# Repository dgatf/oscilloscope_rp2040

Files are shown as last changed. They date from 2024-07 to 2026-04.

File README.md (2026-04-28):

# Oscilloscope RP2040 - OpenHantek protocol

An oscilloscope for the RP2040 that implements the [OpenHantek6022](https://github.com/OpenHantek/OpenHantek6022) protocol.

## Specifications

- Up to 1 MS/s
- 2 channels
- OpenHantek6022-compatible protocol

## Usage

1. Upload the [oscilloscope.uf2](#binaries) firmware to the RP2040.

2. Install OpenHantek. OpenHantek6022 needs RP2040 support:
   [OpenHantek6022 fork](https://github.com/dgatf/OpenHantek6022)

   - Build OpenHantek following the project instructions.
   - Or download prebuilt [binaries](https://github.com/dgatf/OpenHantek6022/releases).

3. The external circuit is optional. If you are **not** using the [external circuit](#external-circuit), copy [RP2040_0_calibration.ini](RP2040_0_calibration.ini) to:

   - Linux: `~/.config/OpenHantek/`
   - Windows: `%USERPROFILE%\.config\OpenHantek`

4. Launch the modified version of OpenHantek6022.

## Pins

- Channel 1: GPIO 26
- Channel 2: GPIO 27
- Calibration signal: GPIO 22
- No conversion: GPIO 19
- Debug enable/disable: GPIO 18
- Debug output: GPIO 16

Without the [external circuit](#external-circuit), the input voltage on GPIO 26 and GPIO 27 must stay between 0 V and 3.3 V.

Debug output is available on GPIO 16 at 115200 bps. To enable debug output, connect GPIO 18 to GND at boot.

The LED is on during capture.

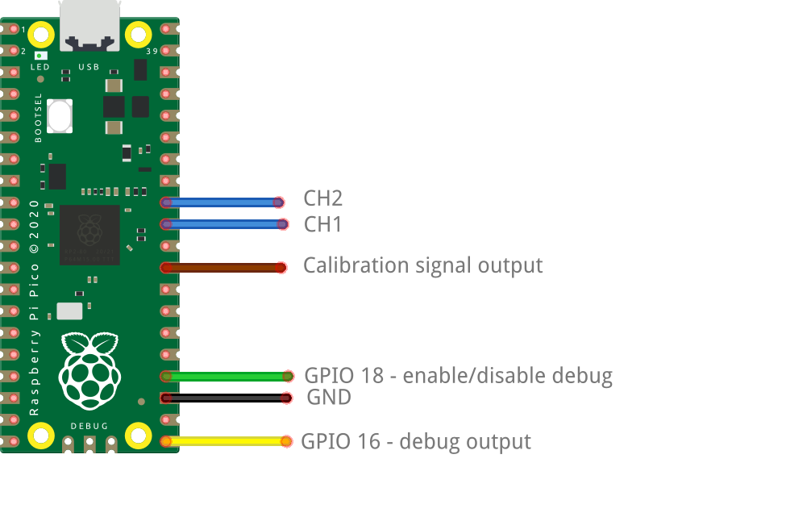
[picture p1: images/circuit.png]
<p align="center"><br></p>

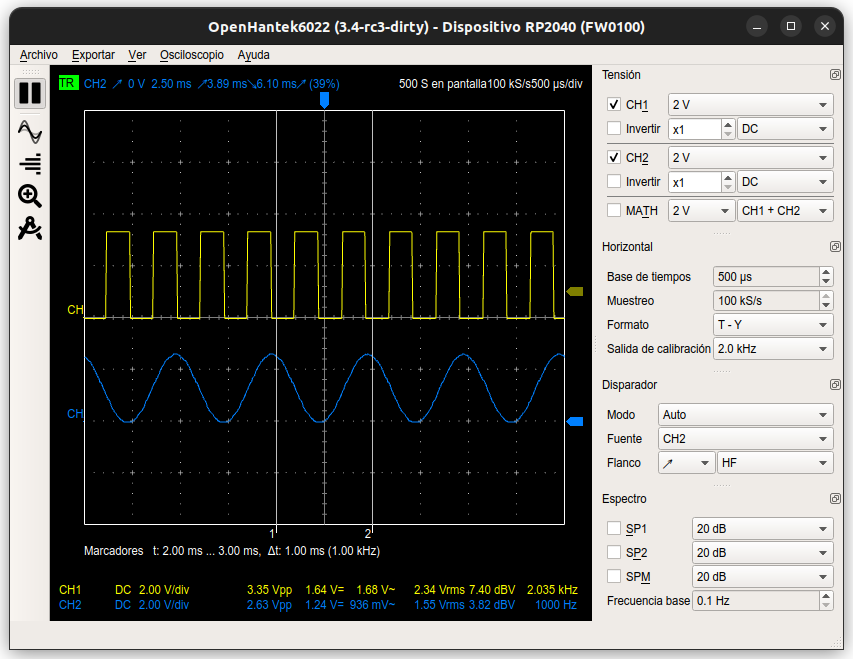
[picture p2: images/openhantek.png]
<p align="center"><br></p>

## External circuit

The external circuit adapts the input signal from ±5 V to the RP2040 ADC range and adds AC/DC coupling.

Signal conversion:

- Step down from 5 V to 3.3 V
- AC/DC coupling
- Optional gain stage
- Center zero voltage at VCC/2

The RP2040 ADC is 12-bit, while OpenHantek expects 8-bit samples. The firmware scales the ADC value from 12 bits to 8 bits. Maximum digital gain is 16. For higher gains, use an additional analog gain stage before centering the signal.

### Materials

- 1 x CD4066 analog switch
- 1 x LM358 op-amp
- 2 x 100 nF ceramic capacitor
- 6 x 10 kΩ resistor
- 2 x 33 kΩ resistor
- 2 x 22 kΩ resistor

If the calibration file was previously copied to the OpenHantek config folder, delete it when using the external circuit.

### Pins

- AC/DC coupling channel 1: GPIO 20
- AC/DC coupling channel 2: GPIO 21

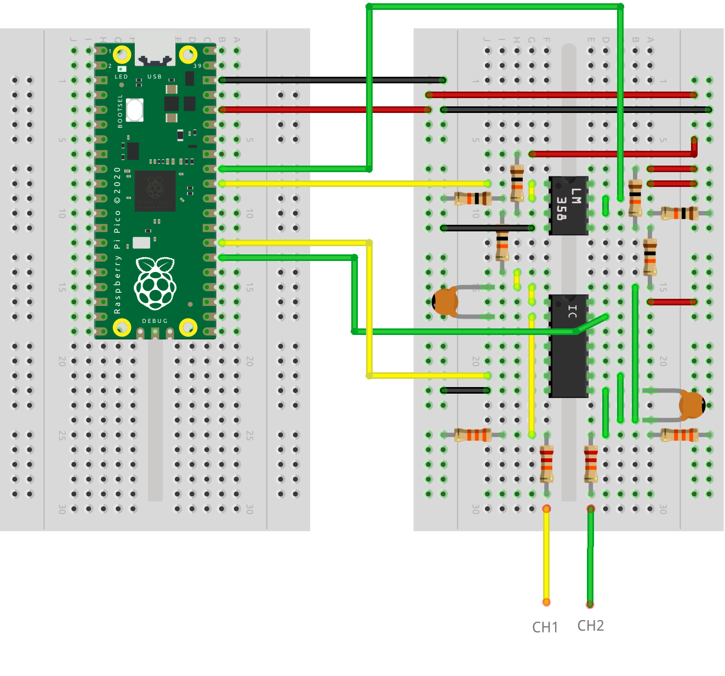
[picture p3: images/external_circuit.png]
<p align="center"><br></p>

## Calibration file OpenHantek

If the external circuit is not used, OpenHantek needs a calibration file to map the RP2040 0-3.3 V ADC input to the expected ±5 V range.

Copy [RP2040_0_calibration.ini](RP2040_0_calibration.ini) to:

- Linux: `~/.config/OpenHantek/`
- Windows: `%USERPROFILE%\.config\OpenHantek`

The calibration file sets:

- Offset: `-127`
- Gain: `0.33`

If using the external circuit, set offsets to `0` and gains to `1`, or delete the calibration file.

## Notes

- The firmware uses fixed-length USB transfers. Streaming is implemented at the application level by re-arming transfers.
- Double-buffered USB transfers improve stability and reduce buffer overflows.
- At 1 MS/s, operation is usable but may still show occasional dropped samples due to USB full-speed bandwidth limits.
- For rates above ~500 kS/s, the ADC operates at higher clock speeds, which may slightly affect accuracy.
- **Linux:** if the device is not detected, install the appropriate [udev rules](udev/99-openhantek.rules) under `/etc/udev/rules.d/` and reconnect the device.
- **Windows:** you may need to install a WinUSB-compatible driver using Zadig.

Example Linux setup:

```bash
sudo cp udev/99-openhantek.rules /etc/udev/rules.d/
sudo udevadm control --reload-rules
sudo udevadm trigger
```

## Binaries

- [RP2040](https://github.com/dgatf/oscilloscope_rp2040/releases)
- [OpenHantek (RP2040)](https://github.com/dgatf/OpenHantek6022/releases)

## References

- [OpenHantek6022](https://github.com/OpenHantek/OpenHantek6022)
- [libsigrok](https://github.com/sigrokproject/libsigrok)
- Das Oszi Protocol - eLinux.org
- [Usb device library](https://github.com/dgatf/usb_library_rp2040)

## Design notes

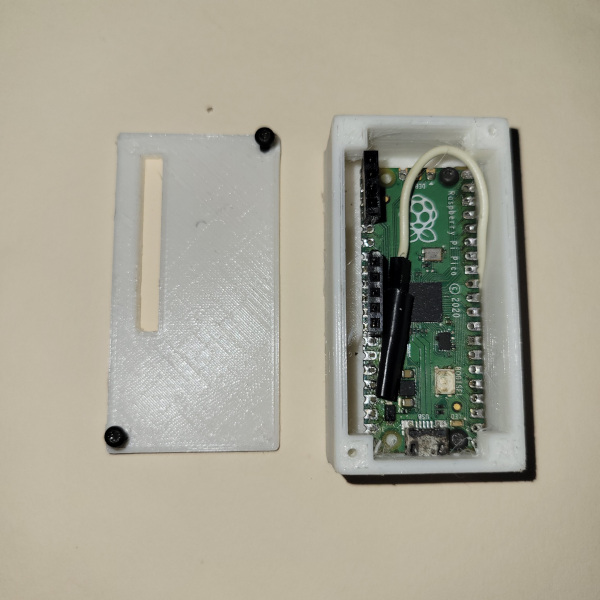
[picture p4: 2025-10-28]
images/case_open.jpg

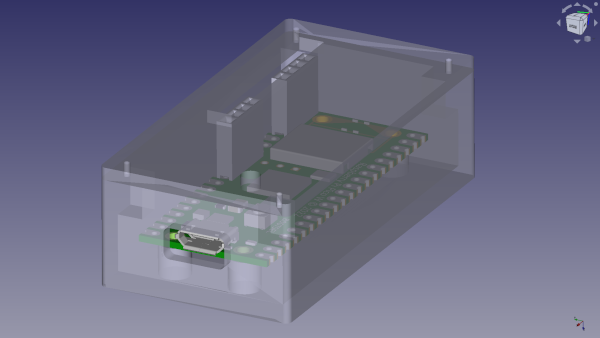
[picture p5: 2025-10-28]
images/3d_model.png

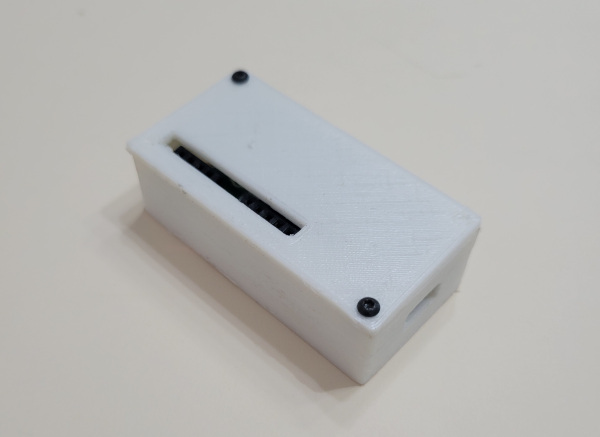
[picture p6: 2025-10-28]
images/case_closed.jpg

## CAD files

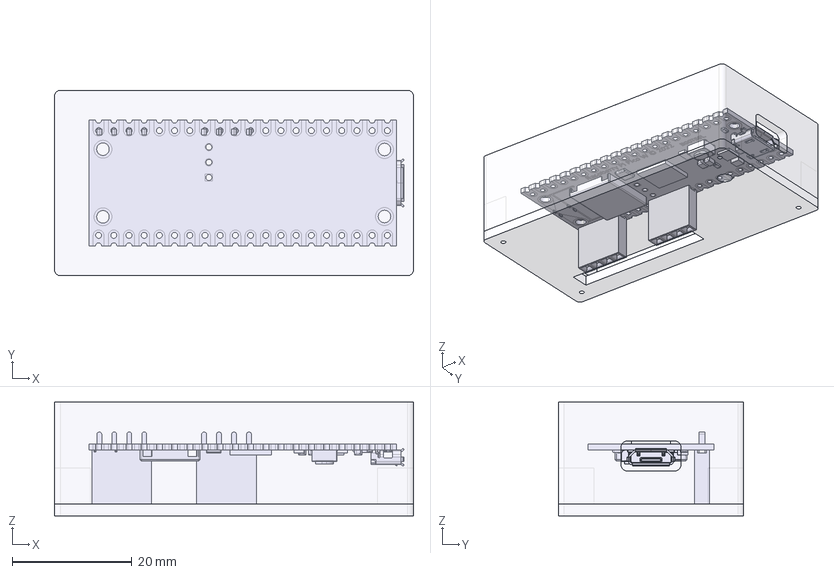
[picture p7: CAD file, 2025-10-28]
case/oscilloscope_case.FCStd
60.0 x 31.0 x 19.0 mm
Lower case
Upper case
rp2040
Female Pin Header v1
Female Pin Header v002

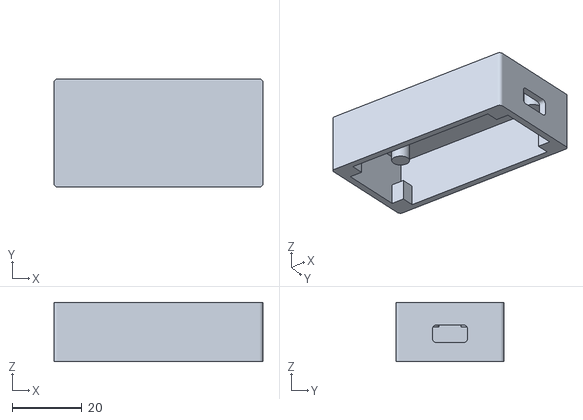
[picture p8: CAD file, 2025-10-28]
case/oscilloscope_case-Lower case.stl
60.0 x 31.0 x 17.0

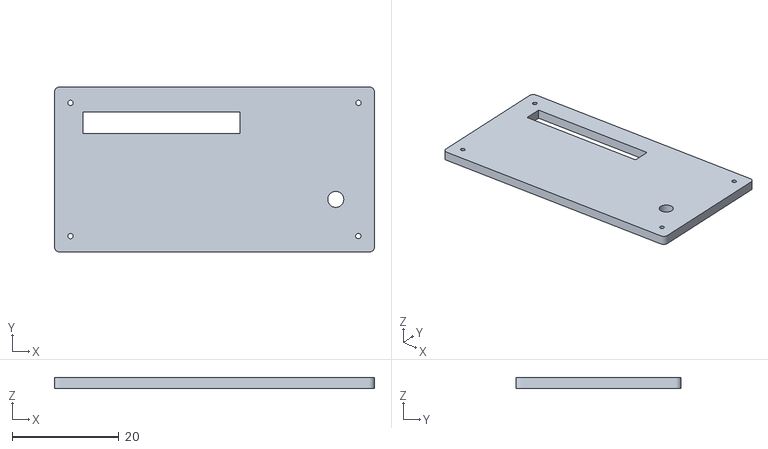
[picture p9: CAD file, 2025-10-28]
case/oscilloscope_case-Upper case.stl
60.0 x 31.0 x 2.00

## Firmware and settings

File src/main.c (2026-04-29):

/*
 * Oscilloscope RP2040
 * Copyright (C) 2024 Daniel Gorbea <danielgorbea@hotmail.com>
 *
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
 * You should have received a copy of the GNU General Public License
 * along with this program.  If not, see <http://www.gnu.org/licenses/>.
 */

#include "hardware/clocks.h"
#include "pico/stdlib.h"
#include "protocol.h"
#include "usb.h"
#include "usb_config.h"

typedef enum gpio_config_t { GPIO_DEBUG_ENABLE = 18, GPIO_NO_CONVERSION = 19 } gpio_config_t;

config_t config;
volatile oscilloscope_config_t oscilloscope_config;
char debug_message[DEBUG_BUFFER_SIZE];

static void set_pin_config(void);

int main() {
    if (clock_get_hz(clk_sys) != 100000000u) set_sys_clock_khz(100000u, true);
    set_pin_config();
    config.is_multicore = false;

    debug_init(115200, debug_message, &config.debug_is_enabled);
    debug("\n\n%s - %s", DEVICE_NAME, PROJECT_VERSION);

    usb_device_init(dev_configs);
    while (!usb_is_configured()) {
        tight_loop_contents();
    }
    gpio_init(PICO_DEFAULT_LED_PIN);
    gpio_set_dir(PICO_DEFAULT_LED_PIN, GPIO_OUT);
    gpio_put(PICO_DEFAULT_LED_PIN, 1);
    sleep_ms(500);
    gpio_put(PICO_DEFAULT_LED_PIN, 0);
    oscilloscope_init();

    while (1) {
        tight_loop_contents();
    }
}

static void set_pin_config(void) {
    gpio_init_mask((1 << GPIO_DEBUG_ENABLE) | (1 << GPIO_NO_CONVERSION));
    gpio_set_dir_masked((1 << GPIO_DEBUG_ENABLE) | (1 << GPIO_NO_CONVERSION), false);
    gpio_pull_up(GPIO_DEBUG_ENABLE);
    gpio_pull_up(GPIO_NO_CONVERSION);
    sleep_ms(1);  // wait for pullup
    config.debug_is_enabled = false;
    config.no_conversion = false;
    if (!gpio_get(GPIO_DEBUG_ENABLE)) config.debug_is_enabled = true;
    if (!gpio_get(GPIO_NO_CONVERSION)) config.no_conversion = true;
}

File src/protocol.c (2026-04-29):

/*
 * Oscilloscope RP2040
 * Copyright (C) 2024 Daniel Gorbea <danielgorbea@hotmail.com>
 *
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
 * You should have received a copy of the GNU General Public License
 * along with this program.  If not, see <http://www.gnu.org/licenses/>.
 */

#include "protocol.h"

#include <string.h>

#include "hardware/adc.h"
#include "hardware/dma.h"
#include "hardware/regs/usb.h"
#include "hardware/structs/usb.h"
#include "pico/multicore.h"
#include "stdio.h"
#include "usb.h"
#include "usb_config.h"

#define usb_hw_set ((usb_hw_t *)hw_set_alias_untyped(usb_hw))
#define usb_hw_clear ((usb_hw_t *)hw_clear_alias_untyped(usb_hw))

extern config_t config;
extern volatile oscilloscope_config_t oscilloscope_config;
extern char debug_message[DEBUG_BUFFER_SIZE];

static volatile uint8_t *buffer_adc;
static volatile uint sample_count = 0, channel_factor[2];
static struct usb_endpoint_configuration *ep;
static uint bof = 0;
static uint64_t ts;
static uint buffer_size, queued_count = 0;
static uint8_t ping_buf[PACKET_CHUNK_SIZE];
static uint8_t pong_buf[PACKET_CHUNK_SIZE];
static uint8_t *fill_buf = ping_buf;
static uint8_t *send_buf = pong_buf;
static uint usb_pos = 0;
static uint buffer_usb_size;

static inline void fill_buffer_usb(volatile uint8_t *buffer_usb, volatile uint8_t *buffer_adc, uint length);

void ep6_in_handler(uint8_t *buf, uint16_t len) {}

static inline void fill_buffer_usb(volatile uint8_t *buffer_usb, volatile uint8_t *buffer_adc, uint length) {
    if (config.no_conversion) {
        memcpy((void *)buffer_usb, (void *)buffer_adc, length);
    } else {
        uint ch_gain;
        for (uint i = 0; i < length; i++) {
            if (oscilloscope_config.channel_mask == 0b11 && (i % 2))
                ch_gain = oscilloscope_config.ch_gain[CHANNEL2];
            else
                ch_gain = oscilloscope_config.ch_gain[CHANNEL1];
            uint16_t *buffer_pos = (void *)buffer_adc;
            buffer_pos += i;
            uint16_t value = (*buffer_pos * ch_gain) >> 4;
            if (value > 0xFF) value = 0xFF;
            *(buffer_usb + i) = value;
        }
    }
}

void control_transfer_handler(uint8_t *buf, volatile struct usb_setup_packet *pkt, uint8_t stage) {
    // debug("\nControl transfer. Stage %u bmRequestType 0x%x bRequest 0x%x wValue 0x%x wIndex 0x%x wLength %u", stage,
    // pkt->bmRequestType, pkt->bRequest, pkt->wValue, pkt->wIndex, pkt->wLength);
    if (stage == STAGE_SETUP) {
        if (pkt->bmRequestType & USB_DIR_IN) {
            ;  // Here prepare buffer to send
        }
    } else if (stage == STAGE_DATA) {
        switch (pkt->bRequest) {
            case 0xA2:  // get calibration
            {
                debug("\nCommand get calibration.");
                break;
            }
            case 0xE0:  // set gain ch1
            {
                uint16_t value = buf[0] | (buf[1] << 8);
                switch (value) {
                    case 0x0701:  // 5V. Gain 1
                    case 0x0601:  // 2V
                    case 0x0501:  // 1V
                        oscilloscope_config.ch_gain[CHANNEL1] = 1;
                        break;
                    case 0x0402:  // 500mV. Gain 2
                        oscilloscope_config.ch_gain[CHANNEL1] = 2;
                        break;
                    case 0x0305:  // 200mV. Gain 5
                        oscilloscope_config.ch_gain[CHANNEL1] = 5;
                        break;
                    case 0x020a:  // 100mV. Gain 10
                    case 0x010a:  // 50mV
                    case 0x000a:  // 20mV
                        oscilloscope_config.ch_gain[CHANNEL1] = 10;
                        break;
                }
                // To use full range (0-255), signal center and step down is done in openhantek with calibration file
                channel_factor[CHANNEL1] = 16 / oscilloscope_config.ch_gain[CHANNEL1];
                debug("\nCommand set gain ch1 (0x%X): %u", value, oscilloscope_config.ch_gain[CHANNEL1]);
                break;
            }
            case 0xE1:  // set gain ch2
            {
                uint16_t value = buf[0] | (buf[1] << 8);
                switch (value) {
                    case 0x0701:  // 5V. Gain 1
                    case 0x0601:  // 2V
                    case 0x0501:  // 1V
                        oscilloscope_config.ch_gain[CHANNEL2] = 1;
                        break;
                    case 0x0402:  // 500mV. Gain 2
                        oscilloscope_config.ch_gain[CHANNEL2] = 2;
                        break;
                    case 0x0305:  // 200mV. Gain 5
                        oscilloscope_config.ch_gain[CHANNEL2] = 5;
                        break;
                    case 0x020a:  // 100mV. Gain 10
                    case 0x010a:  // 50mV
                    case 0x000a:  // 20mV
                        oscilloscope_config.ch_gain[CHANNEL2] = 10;
                        break;
                }
                // To use full range (0-255), signal center and step down is done in openhantek with calibration file
                channel_factor[CHANNEL2] = 16 / oscilloscope_config.ch_gain[CHANNEL2];
                debug("\nCommand set gain ch2 (0x%X): %u", value, oscilloscope_config.ch_gain[CHANNEL2]);
                break;
            }
            case 0xE2:  // set samplerate
            {
                uint16_t value = buf[0] | (buf[1] << 8);
                bool handled = true;
                switch (value) {
                    case 0x0365:
                    case 0x0065:  // 10 downsampling
                        oscilloscope_config.samplerate = 10e3;
                        break;
                    case 0x0446:
                    case 0x0166:  // 10 downsampling
                        oscilloscope_config.samplerate = 20e3;
                        break;
                    case 0x0569:
                    case 0x0269:  // 10 downsampling
                        oscilloscope_config.samplerate = 50e3;
                        break;
                    case 0x066E:
                        oscilloscope_config.samplerate = 100e3;
                        break;
                    case 0x0778:
                        oscilloscope_config.samplerate = 200e3;
                        break;
                    case 0x88C:
                        oscilloscope_config.samplerate = 400e3;
                        break;
                    case 0x0896:
                        oscilloscope_config.samplerate = 500e3;
                        break;
                    case 0x0901:
                        oscilloscope_config.samplerate = 1e6;
                        break;
                    case 0x0A02:
                        oscilloscope_config.samplerate = 2e6;
                        break;
                    default:
                        handled = false;
                }
                if (handled) {
                    debug("\nCommand samplerate: 0x%X", value);
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

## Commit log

2024-10-05 Pause adc to allow higer rates and overclock only if needed
2025-10-28 Add 3D print case
    [oscilloscope_case-Lower case.stl, oscilloscope_case-Upper case.stl, oscilloscope_case.FCStd]
2026-03-29 fix: correct samplerate scaling and DMA IRQ handling
    [oscilloscope.c]
2026-04-15 Fix usb double buffer
    [protocol.c]
2026-04-28 Update oscilloscope USB transfer handling
    Integrate the new fixed-length USB transfer model in the oscilloscope path.
    Use queued sample accounting and endpoint busy checks to re-arm EP6 IN transfers
    without relying on stream mode.
    Also add overflow accounting for ADC ring overrun during USB backpressure.
    [main.c, oscilloscope.c, protocol.c]
2026-04-28 Fix sample loss at 1MS/s: replace single USB buffer with ping-pong buffer (#3)
    Agent-Logs-Url: https://github.com/dgatf/oscilloscope_rp2040/sessions/209bcbd3-30de-4a15-98cf-e2449e1d0019
    [protocol.c]
2026-04-30 Update USB VID/PID

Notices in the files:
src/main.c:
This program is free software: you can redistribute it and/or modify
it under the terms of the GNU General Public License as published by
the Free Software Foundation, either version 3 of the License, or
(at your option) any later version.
